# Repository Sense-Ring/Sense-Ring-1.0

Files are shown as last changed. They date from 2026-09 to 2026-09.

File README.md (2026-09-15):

# SenseRing

**Open-source smart ring for biosensing and motion tracking, packed into a format you can build, program, and improve.**

SenseRing is a compact, finger-worn research and development platform built around the Nordic Semiconductor [nRF52832](https://www.nordicsemi.com/Products/nRF52832) Bluetooth Low Energy SoC. Its custom electronics combine optical pulse sensing, motion sensing, wireless connectivity, battery charging, and power management in a wearable form factor.

Use it to explore photoplethysmography (PPG), heart-rate and SpO₂ algorithm development, activity and gesture recognition, low-power Bluetooth applications, and new wearable interfaces. 

<p align="center">
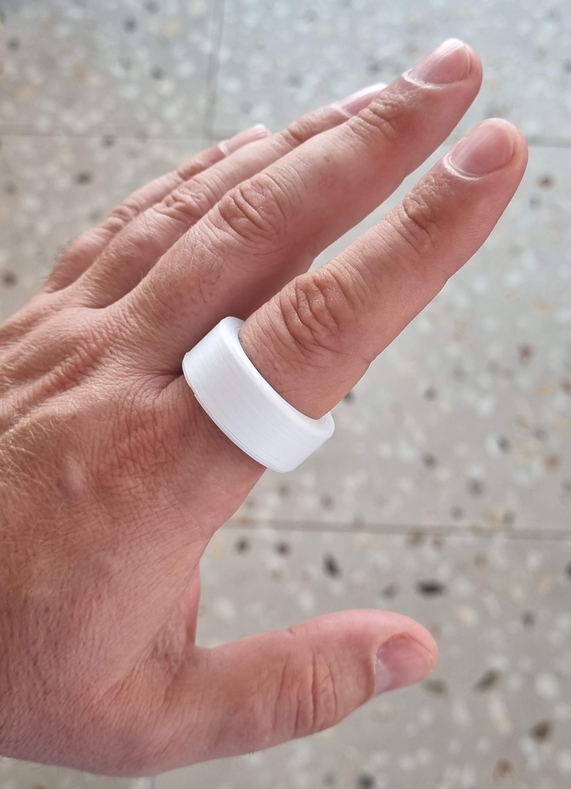
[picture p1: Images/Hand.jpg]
SenseRing 1.0 prototype worn on a finger
  
</p>

> [!IMPORTANT]
> SenseRing is an experimental research platform, not a certified medical device. Do not use it for diagnosis, treatment, or safety-critical monitoring.

## Hardware features

| Function | Implementation |
| --- | --- |
| Processing and wireless | [nRF52832](https://www.nordicsemi.com/Products/nRF52832), 64 MHz Arm Cortex-M4F with Bluetooth Low Energy and a 2.4 GHz radio |
| Optical sensing | [MAX30102](https://www.analog.com/en/products/max30102.html) integrated red/IR PPG sensor for pulse-oximetry and heart-rate experiments |
| Motion sensing | [BMA530](https://www.bosch-sensortec.com/en/products/motion-sensors/accelerometers/bma530) ultra-compact, low-power 3-axis accelerometer with motion interrupts and step-counting support |
| Battery charging | [BQ25180](https://www.ti.com/product/BQ25180) single-cell Li-ion/LiPo charger with I²C control, power path, and ship mode |
| Power and protection | [AP6683](https://www.lcsc.com/datasheet/C2849565.pdf) battery protection, [XC6504A1819R-G](https://www.lcsc.com/datasheet/C5142782.pdf) 1.8 V LDO, and two [WS4622C](https://www.lcsc.com/datasheet/C2939859.pdf) load switches for the PPG LED supply and battery-measurement circuit |
| RF front end | [2450AT18B100E](https://www.lcsc.com/datasheet/C2917717.pdf) 2.4 GHz chip antenna and matching circuit |
| Debugging and test | TC2030 SWD footprint for programming and charging, compatible with [Segger J-Link 6-pin Needle Adapters](https://www.segger.com/products/debug-probes/j-link/accessories/adapters/6-pin-needle-adapter/) |
|Battery| 31mAh curved [GRP1607034](https://www.grepow.com/wearables/smart-ring.html)|
| PCB | 14.9 × 10 mm, two copper layers, mostly fine-pitch WLCSP and 0201 components |

<p align="center">
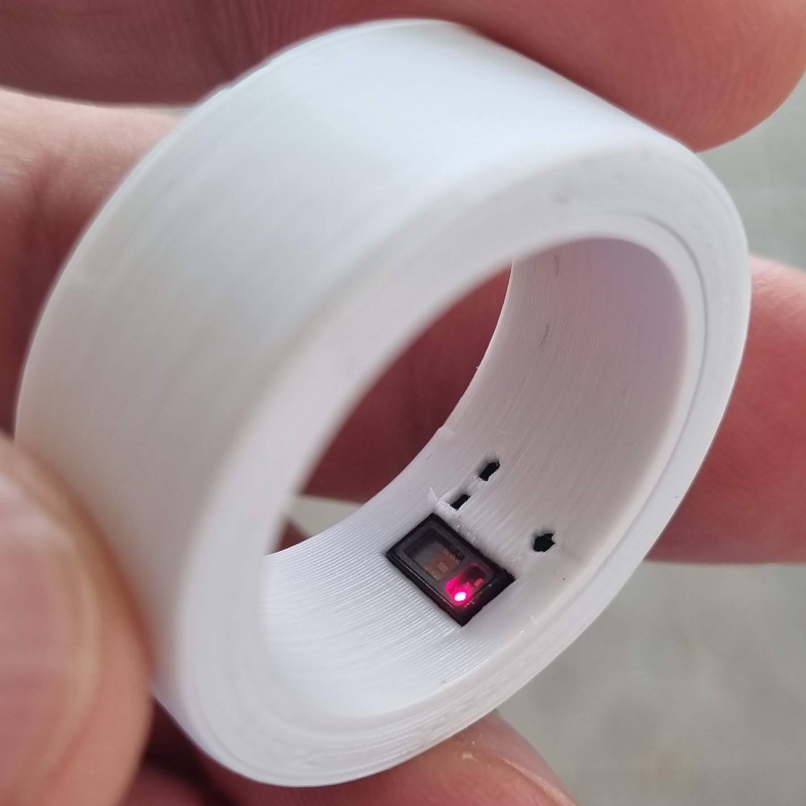
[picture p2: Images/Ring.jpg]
SenseRing optical sensor operating inside the ring
  
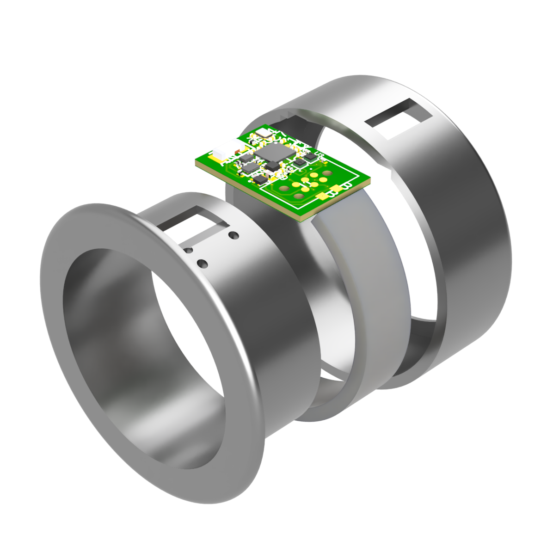
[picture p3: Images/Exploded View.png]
Exploded rendering of the SenseRing enclosure, battery, and circuit board
  
</p>

## Architecture

The nRF52832 communicates with the PPG sensor, accelerometer, and charger over a shared I²C bus. Dedicated interrupt lines allow the sensors and PMIC to wake the processor. The PPG LED supply and battery-measurement divider are independently switchable, limiting leakage when those functions are idle.

<p align="center">
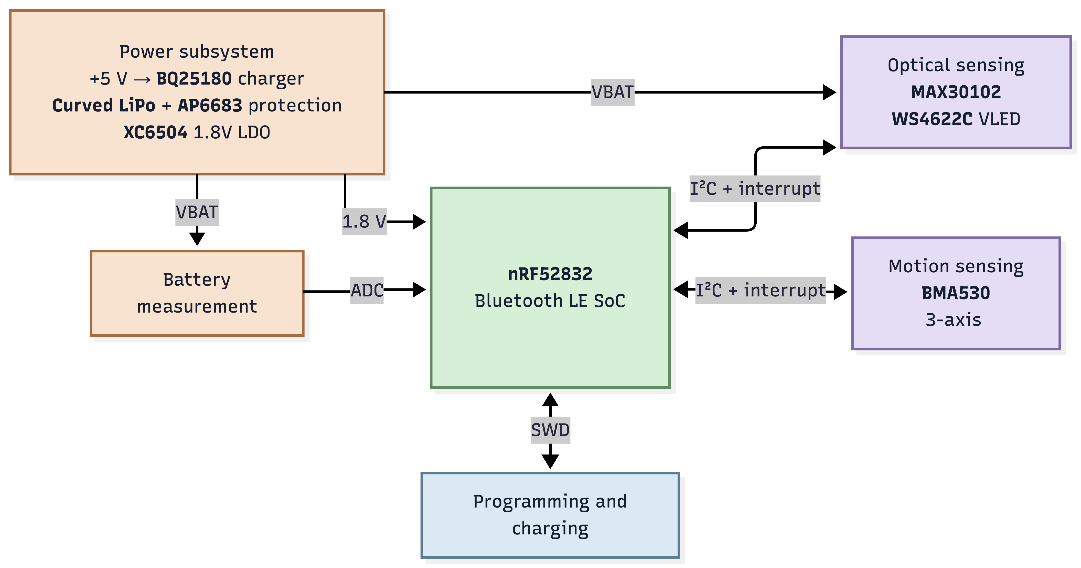
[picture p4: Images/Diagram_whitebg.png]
SenseRing 1.0 diagram
  
</p>

| Signal | nRF52832 pin | Connected function |
| --- | --- | --- |
| `SDA` | `P0.29 / AIN5` | MAX30102, BMA530, and BQ25180 data |
| `SCL` | `P0.28 / AIN4` | MAX30102, BMA530, and BQ25180 clock |
| `PPG_INT` | `P0.06` | MAX30102 interrupt |
| `IMU_INT` | `P0.18` | BMA530 interrupt |
| `PMIC_INT` | `P0.15` | BQ25180 interrupt |
| `LED_EN` | `P0.01` | PPG LED-rail load switch |
| `VBAT_EN` | `P0.00` | Battery-divider load switch |
| `VBAT_MEAS` | `P0.05 / AIN3` | Battery-voltage ADC input |
| `TX` test pad | `P0.30 / AIN6` | Firmware-assignable test/UART signal |
| `RX` test pad | `P0.25` | Firmware-assignable test/UART signal |

## Battery benchmark

Measured with a Power Profiler Kit II supplying the board in place of the 31 mAh cell, running the normal cycle: 15 s window, five readings, LED rail down, 90 s pause. IMU on throughout, BLE advertising. This replaces the estimate in [`ARCHITECTURE.md`](Software/Firmware/src/ARCHITECTURE.md) §5.1.1 (~305 µA, four days).

<p align="center">
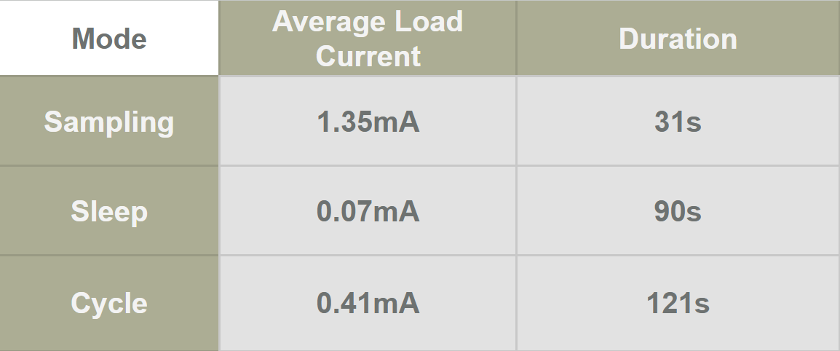
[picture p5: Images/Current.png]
Average load current per mode: 1.35 mA sampling, 0.07 mA sleep, 0.41 mA over the full cycle
  
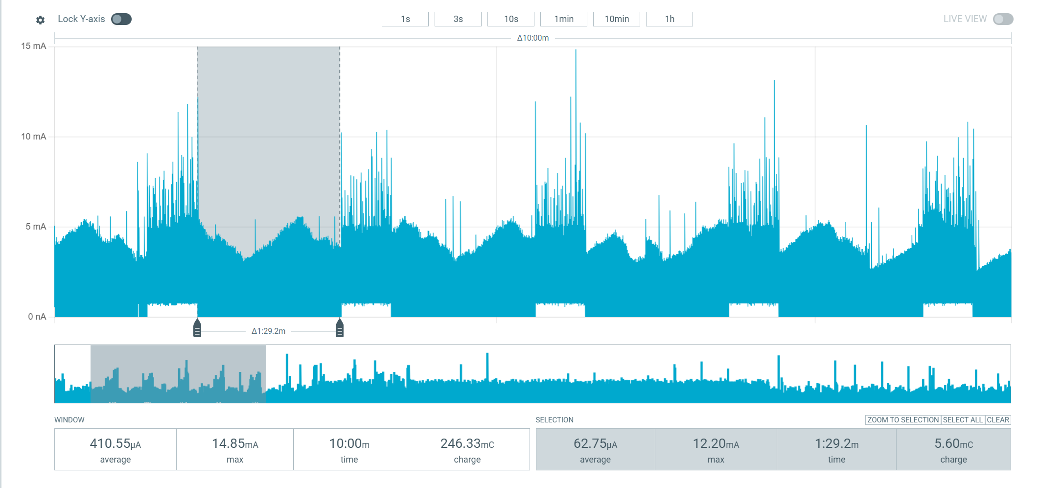
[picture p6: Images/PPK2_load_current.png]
Power Profiler Kit II capture of ten minutes of SenseRing load current
  
</p>

| Mode | Average load current | Duration |
| --- | --- | --- |
| Sampling (LED rail up) | 1.35 mA | 31 s |
| Sleep (IMU and BLE only) | 0.07 mA | 90 s |
| **Full cycle** | **0.41 mA** | **121 s** |

31 s of sampling against a 90 s pause is 25.6 % duty. Over ten minutes the capture reads 410.55 µA average, 246.33 mC, 14.85 mA peak. One full pause reads 62.75 µA: the BMA530 at ~15 µA, the nRF52832 idle, and both load switches open.

### Runtime on 31 mAh

| Quantity | Value |
| --- | --- |
| Charge per cycle | 13.7 µAh (~49 mC) |
| Cycles per charge | ~2,250 |
| Readings per charge | ~11,250 |
| **Runtime, default cadence** | **~75 h (3.1 days)** |
| Sampling continuously | ~23 h |
| Sleep floor only | ~440 h (18 days) |

## Repository contents

| Path | Contents |
| --- | --- |
| [`Hardware/`](Hardware/) | Autodesk Fusion Electronics/EAGLE schematic and board sources (`.fsch`, `.fbrd`, `.sch`, `.brd`) and a [schematic PDF](Hardware/SenseRing_schematic.pdf) |
| [`Mechanical/`](Mechanical/) | Complete Fusion 360 archive, STEP and OBJ assemblies, printable shell STLs, board and battery models, and two programming-fixture STLs |
| [`Images/`](Images/) | Prototype photographs and the exploded assembly render used in this README |
| [`Software/Firmware/`](Software/Firmware/) | nRF52832 firmware: sampling, the vitals estimator, the flash log, and the BLE peripheral |
| [`Software/App/`](Software/App/) | Android companion app: collects the ring's buffered log over BLE, stores it locally and charts it |

## Working with the design

### 1. Clone the repository

```bash
git clone https://github.com/Sense-Ring/Sense-Ring-1.0.git
cd Sense-Ring-1.0
```

### 2. Inspect or modify the electronics

- Open [`SenseRing.fsch`](Hardware/SenseRing.fsch) and [`SenseRing.fbrd`](Hardware/SenseRing.fbrd) in Autodesk Fusion Electronics.
- The XML [`SenseRing.sch`](Hardware/SenseRing.sch) and [`SenseRing.brd`](Hardware/SenseRing.brd) files are also included for EAGLE-compatible workflows.
- For a quick review without CAD software, open [`SenseRing_schematic.pdf`](Hardware/SenseRing_schematic.pdf).

### 3. Inspect or print the enclosure

- Open [`RingCase.f3z`](Mechanical/RingCase.f3z) for the editable Fusion 360 assembly.
- Use [`RingCase.step`](Mechanical/RingCase.step) or [`RingCase.obj`](Mechanical/RingCase.obj) for interchange with other CAD tools.
- Print [`InnerShell.stl`](Mechanical/InnerShell.stl) and [`OuterShell.stl`](Mechanical/OuterShell.stl) for the enclosure.
- The repository also provides board and battery reference models and two-piece programming-fixture STLs.

### 4. Program and debug

The PCB exposes `SWDIO`, `SWDCLK`, `RESET`, 1.8 V, +5 V, and GND through its TC2030 programming footprint. Use a compatible SWD debugger and verify the target-voltage and power configuration before connecting it to the board.

## Manufacturing notes

This is a miniaturized wearable design using WLCSP/BGA packages and 0201 passives. Professional PCB assembly and appropriate inspection equipment are strongly recommended.

The current repository does **not** include production exports such as Gerbers, drill files, a bill of materials, or pick-and-place data. Generate and verify those outputs from the hardware sources before ordering boards. Battery selection, charge settings, clearances, enclosure material, skin contact, RF performance, and optical performance must all be validated for your implementation.

## Contributing

Issues, design reviews, firmware ports, enclosure variants, measurements, and reproducibility notes are welcome. When reporting a hardware problem, please include the board revision, power source, programmer/debugger, and enough measurements or logs to reproduce it.

## License

SenseRing 1.0 is open source and distributed under the [GNU General Public License v3.0](LICENSE). It is provided as-is, without warranty.

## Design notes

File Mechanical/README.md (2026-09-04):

Mechanical files for the ring case, programming fixture and board+battery.

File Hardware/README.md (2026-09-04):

Hardware design files for Fusion 360 / Eagle CAD

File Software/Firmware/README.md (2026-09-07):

# SenseRing firmware

Zephyr OS app for the SenseRing 1.0: an nRF52832 that measures heart rate and blood
oxygen from the finger, stores every reading to on-board flash, and hands the
log to a phone over Bluetooth.

The ring never decides what a reading means. It measures, records *why* it
refused when it could not measure, and buffers until something collects.

## How it works, in five lines

- Two LEDs and a photodiode (MAX30102) sample the finger at 25 Hz.
- Every ~2 minutes the ring wakes, fills a 15-second window, and reports five
  readings from it, then puts the LEDs down. That is ~26% duty on a 31 mAh cell.
- Autocorrelation over the window gives the pulse period and a 0–1000
  confidence; the red/IR ratio gives SpO₂.
- Each reading becomes a 16-byte record in a flash ring buffer — about **4 days**
  of readings, 14,592 records — carrying its own confidence, perfusion, contact
  state, step delta and movement bucket.
- A client subscribes over BLE, replays the backlog, and acknowledges it. Only
  then does the ring erase.

An accelerometer (BMA530) runs continuously at ~15 µA: it decides when the hand
is still enough to be worth measuring, and tags every record with how much it
moved.

**`src/ARCHITECTURE.md` is the real documentation** — one section per source
file, explaining the reasoning rather than restating the code. Start at §0 if
embedded work is new to you.

## Hardware

Board `sensering_v29`, defined in-tree under `boards/`. The schematic this
firmware was written against is `.sense/SenseRing v49.pdf`, and it is the
authority whenever it and a document disagree — the version numbers differ, and
the schematic is the one that matches the pinout. The repository's own hardware
sources live in [`Hardware/`](../../Hardware/).

| | |
|---|---|
| MCU | nRF52832 (QFAA), 512 KB flash / 64 KB RAM, no DC/DC inductor |
| PPG | MAX30102, I²C `0x57`, on a switched VLED+ rail |
| IMU | BMA530, I²C `0x18` |
| PMIC | BQ25180, 31 mAh LiPo |
| Rail | XC6504 1.8 V LDO |
| Console | **RTT only — the board has no UART** |

## Building

The toolchain is the nRF Connect SDK (Zephyr). Built against **NCS v3.3.1**.

```
west build -b sensering_v29 -- -DBOARD_ROOT=<path to this repo>
```

`build_env.bat` wraps that for a Windows-side NCS install — edit the two NCS
paths at the top; it works out the repo location itself. It exists because `west` and the toolchain live on the
Windows side, so builds have to run through `cmd.exe` rather than from a WSL
shell with exported variables — bash environment variables do not propagate to
Windows processes.

A clean build currently produces:

```
FLASH:  209 232 B / 248 KB   82.4%
RAM:     43 428 B /  64 KB   66.3%
```

The `mcuboot` and `image-0` partitions remain in the map and the app links over
them; the former OTA slots were reclaimed for the vitals log, so **there is no
OTA path** — flashing needs a J-Link.

```
west flash          # J-Link, nRF52832_xxAA at 1000 kHz
```

## Tests

The pure-arithmetic halves run on a host compiler in about a second, with no
Zephyr, board or NCS toolchain:

```
cd tests/host
make            # everything      — 63,377 checks
make vitals     # the rate estimator, against synthetic PPG
make flash      # the log's ring arithmetic, against a modelled NOR part
make sweep      # candidate BPM floors side by side
```

The flash model only ever clears bits, exactly like the part, so writing into a
slot nobody erased first fails the way hardware fails. Neither target is wired
into `CMakeLists.txt` — deliberately, because a test that needs the full
toolchain is a test nobody runs. Nothing covers the duty cycle or the BLE
protocol; both need a kernel.

`tests/bench/` holds bring-up modes that are kept but not compiled — an I²C bus
scan and IMU probe, for a board revision that fails to come up.

## Bluetooth

Standard Heart Rate (`0x180D`) and Battery services, plus a custom service at
`f1a00001-9c1b-4d3e-a7b2-5e8c6d9f0a11`:

| Characteristic | Purpose |
|---|---|
| `…0002` | live vitals package — byte-identical to the flash record |
| `…0003` | live motion — timestamp, x/y/z, step total |
| `…0004` | control — set the clock, request a replay, acknowledge one |
| `…0005` | history — the framed, resumable backlog replay |
| `…0006` | status — cell level and step total |

The custom characteristics are encryption-gated and bonds persist. The ring
decides who may pair: only with no bond yet, or inside a two-minute window
opened by a power-on boot.

Live streaming is **off** by default (`BLE_LIVE_STREAM` in `main.c`) — the radio
carries nothing per reading, and data leaves in page-sized batches.

## Licence

This firmware is MIT — see [`LICENSE`](LICENSE). The SenseRing 1.0 repository as
a whole is GPLv3; MIT is compatible with that, so a combined work still
distributes under the GPL.

## Layout

```
src/            firmware, one .c per subsystem, plus ARCHITECTURE.md
boards/         the sensering_v29 board definition and DTS
tests/host/     host-compiled tests for vitals.c and flash_store.c
tests/bench/    uncompiled bring-up helpers
prj.conf        Kconfig, every line commented with why
.sense/         schematic
LICENSE         MIT
```

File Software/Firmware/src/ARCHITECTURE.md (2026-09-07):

# SenseRing firmware — how `src/` works and why

**New here? Read §0 in full. It assumes no embedded experience and it is the
only part of this document that doesn't.** Everything after it is a reference
manual: one section per source file, explaining the reasoning rather than
restating the code. Read those next to the source; the headings match the
function names.

Written against the **v49 schematic** (`.sense/SenseRing v49.pdf`) and
`boards/sensering_v29/sensering_v29.dts`. The version numbers disagree — v49 is
the one that matches the pinout, and the schematic is the authority whenever it
and this document differ.

---

## 0. Start here

### 0.1 What the thing is

A ring that measures the wearer's heart rate and blood oxygen every couple of
minutes, stores the readings, and hands them to a phone.

That's it. Everything below is consequence.

The ring cannot reach the internet, so it talks to a phone over Bluetooth, and
whatever the phone is connected to decides what the readings mean.

```
  ring  ──Bluetooth──>  phone  ──> whatever consumes the data
 measures               relays
 and stores
```

### 0.2 Two ideas explain most of the code

**Idea one: the battery is 31 milliamp-hours.** For scale, a phone battery is
about 4000. If the ring drew what a phone draws it would last under a minute.
So the ring spends most of its life asleep with everything switched off, wakes
up, measures for half a minute, and goes back to sleep. Almost every strange
decision in this codebase — why the LEDs are on a switch, why the radio listens
only once a second, why a measurement is 15 seconds and not 60 — traces back to
this number.

**Idea two: the ring is not the decider.** It is tempting to make the ring
clever: have it interpret the readings it takes. It does not. The ring measures,
stores, and says "come and get the data." Interpretation belongs to whatever
consumes the log, because that can be updated, can see history, and can be
wrong without a firmware release.

This is why you will see the code repeatedly refuse to draw conclusions, and why
it works so hard to record *why* it refused rather than just going quiet. The
one judgement it does make is about its own evidence -- whether a window
produced a pulse it believes -- and §4.5 is where that line is drawn.

### 0.3 How a heart rate actually gets measured

No prior knowledge needed for this; it is genuinely simple in outline.

1. **Shine a light into the finger.** Two LEDs, one red and one infrared, sit
   against the skin. A photodiode next to them measures how much light comes
   back. This is the MAX30102 part, driven by `ppg.c`.
2. **Blood absorbs light.** Every heartbeat pushes a pulse of blood through the
   finger, so slightly less light comes back at each beat. The signal is a big
   steady value with a *tiny* ripple on it — the ripple is well under 1% of the
   total on a ring. That ripple is the pulse.
3. **Collect 15 seconds of it.** At 25 samples a second that's 375 numbers.
4. **Throw away the slow drift.** Breathing moves the signal far more than the
   heartbeat does, so a filter removes anything slower than a plausible pulse.
5. **Find the repeat.** Slide the 15 seconds of signal against itself and see
   at what shift it best matches itself. That shift is the time between beats.
   60 divided by it is the heart rate. This is `vitals.c`, and it is called
   *autocorrelation*.
6. **Say how sure you are.** How well the signal matched itself is a confidence
   number, 0–1000. Below 500 the firmware will not call it a heart rate.

Blood oxygen (SpO₂) rides along free: oxygenated blood absorbs red and infrared
differently, so the ratio of the two ripples tracks saturation.

### 0.4 What happens to a reading

```
  measure ──> is it believable? ──yes──> write to flash ──> notify phone (live)
                     │
                     └──no──> write the *refusal* to flash, with the reason
```

Two things worth understanding, because they are unusual:

**Refusals are stored, not skipped.** If the ring is not being worn, or the
pulse is too weak, the firmware writes a record saying so. A log with a hole in
it and a log that says "I looked and saw nothing" look identical from the
outside, and only one of them is useful. The reasons are: not worn, no pulse
found, pulse too weak, and pulse slower than the band.

**Flash is a queue, not a diary.** Records go into a ring buffer in flash and
stay there until the phone confirms it has them. Only then does the ring reuse
that space. If the phone is away for a day, the readings wait. This is the
"buffer and flush" architecture, and §5A is where it lives.

### 0.5 Vocabulary

The terms that will otherwise stop you, in the order you'll meet them. Appendix
B is the full glossary.

| Term | What it means here |
|---|---|
| **PPG** | photoplethysmography — the shine-a-light-at-a-finger technique in §0.3 |
| **I2C** | a two-wire bus the chip uses to talk to the sensors. Think of it as a very slow, very simple network with addresses |
| **GPIO** | a single pin the chip can drive high or low. Used here to switch sensor power on and off |
| **DC / AC** | the steady part of a signal / the ripple on top. The pulse is the AC part |
| **perfusion index (PI)** | how big the ripple is compared to the steady part, in parts per thousand. A ring sees ~0.2–1%; a fingertip clip sees ten times that |
| **duty cycle** | what fraction of the time something is switched on. The whole power budget is duty cycle arithmetic |
| **RTT** | a debug console that works over the programming cable. This board has no serial port, so RTT is the only way to watch it run |
| **GATT / characteristic** | Bluetooth's way of exposing named values a phone can read, write, or subscribe to |
| **notification** | the ring pushing a value to the phone without being asked |
| **flash page** | flash memory can be written a byte at a time but only *erased* a whole page (4KB) at a time. This one fact shapes all of `flash_store.c` |
| **Kconfig / `prj.conf`** | build-time switches for the operating system (Zephyr). Appendix C explains the ones that matter |

### 0.6 What to read next

| If you want to… | Read |
|---|---|
| See the board and the software in one page each | §1 |
| Understand a specific source file | §2–§5C, one per file, in dependency order |
| Know what is *not* built | §6 |
| Look up a pin | Appendix A |
| Look up a word | Appendix B |
| Understand the build, the board file, the partitions | Appendix C |

The per-file sections are `battery.c` §2, `ppg.c` §3, `imu.c` §3A, `vitals.c`
§4, `main.c` §5, `flash_store.c` §5A, `ble.c` §5B and `wallclock.c` §5C.

---

## 0A. What is measured, and what is only argued

Kept near the top because the rest of this document describes how things work,
which is a different question from how well they have been shown to.

**The short version: the ring measures correctly and the data path closes. The
power budget is the one number the whole design is argued from, and it has never
been put on a probe.**

### 0A.1 What is built, and what backs it

| Area | State | Evidence |
|---|---|---|
| Board bring-up — I2C, SAADC, flash, RTT, BLE | works on hardware | boots, advertises, logs, stores |
| `battery.c` — divider, gating, curve | works on hardware | reports plausible mV and % |
| `imu.c` — BMA530 read path | works on hardware | §3A; bus scan saw `0x18`, chip ID `0xC2`, \|a\| ≈ 1000 at rest |
| IMU step count | **wired up, never walked** | §3A.8; read and notified, but never checked against a human walking a known count |
| `vitals.c` — heart rate | works on hardware | 71bpm off a real finger, confidence and optics both plausible |
| `vitals.c` — the arithmetic | host-tested | `tests/host`, 1026 synthetic windows, 0 wrong |
| `vitals.c` — SpO₂ | **arithmetic sound, curve uncalibrated** | §4.4; Maxim's fit for Maxim's optics |
| Contact detection | **works, threshold still a guess** | §4.5; `VITALS_CONTACT_IR_DC_ON` has never been checked against a range of real fingers |
| Duty cycle, flash log | works on hardware | §5.1, §5A |
| `flash_store.c` — ring arithmetic, ack and erase | host-tested | `tests/host`, two laps at the real geometry against a modelled NOR part |
| `ble.c` — advertising, services, live notifications | works on hardware | §5B |
| `ble.c` — who may pair, who may stay connected | **written, never met a handset** | §5B.5a; the pairing gate and the 30-second security deadline both build clean, and neither has been exercised on the radio |
| **Buffer → phone → acknowledge → reclaim** | works on hardware | §5A.8, §5B.6 |
| Connection power (slave latency) | works on hardware | §5B.7; a real phone granted the idle regime |
| Power budget | **estimated, never measured** | §5.1.1 |

### 0A.2 The gap that matters

**Every power number in this document is arithmetic, not measurement.** §5.1.1
predicts ~305µA and about four days, and flags that its largest single term is
quoted at a shorter LED pulse width than this firmware actually uses — so the
real figure is likely worse. Until a current probe goes on the cell, every
decision justified by "this saves battery" is justified by a spreadsheet.

**Two worn observations say the spreadsheet is wrong by ~3.7×.** They implied
~2.1 and ~1.5 days respectively, both with about a third of the time off the
finger — so a worn-state draw near 1.14mA against a predicted 305µA. Both are
gauge readings, and the gauge itself is untrusted (§2.5), so treat ~1 day as a
direction rather than a measurement. The important part is the sign: **every
number in §5.1.1 is optimistic, and nothing in this document accounts for
why.**

### 0A.3 Known limits, in the order they would hurt

| | Limit | Where |
|---|---|---|
| 0 | **The ring can reset roughly every 28 minutes and the firmware cannot say why.** Observed at 60% battery and not under radio load. `RESETREAS`, a delivery hold mark and a log that survives a reset are all written against it, and the mechanism is still open — brownout, a supply interruption and the BQ25180 are all live. | §5A.1, §5A.4a |
| 1 | **No activity signal reaches the vitals path.** 120bpm from climbing stairs and 120bpm at rest are the same number to this firmware. Acceleration and step count are read, notified and stored beside the reading, but nothing on the ring *consumes* them. | §6 |
| 2 | **The power budget has never been measured.** | §5.1.1 |
| 3 | **SpO₂ is uncalibrated.** The ratio arithmetic is sound; mapping it to a percentage is a vendor fit for a different sensor's optics. Trend, not vital sign. | §4.4 |
| 4 | **The step counter has never been walked.** Presented as data on no evidence. | §3A.8 |
| 5 | **`VITALS_CONTACT_IR_DC_ON` decides whether the ring measures at all, and is a bench guess.** Every cycle logs the measured IR DC beside it, so a wrong threshold is visible rather than silent. | §5.1 |
| 6 | **The pairing gate rests on a bit that cannot tell a power cycle from a brownout.** `RESETREAS` reads zero for both, so a cell that sags far enough to reset the SoC opens a two-minute pairing window nobody asked for. Bounded, but it is the assumption the whole gate stands on. Beside it: Zephyr's stock HRS is still unencrypted, so `0x180D` is subscribable by any scanner the moment `BLE_LIVE_STREAM` goes to 1 for bench work. | §5B.5a, §6 |
| 7 | RTT is 4KB, `NO_BLOCK_SKIP` — raised from the 1KB a 35-record dump overran, but a full-page dump is still tens of KB and drops silently. | §5.5.1 |
| 8 | **Delivery depends on the phone being in range.** If the phone is in another room nothing arrives; the records are buffered and delivered later. This is a property of the architecture, not a bug in it, and it has to be stated to whoever builds on the device. | §5A.8 |

Item 0 is the one that stops the data being trustworthy at all. Item 1 is the
one that most limits what can be built on top of the log: without activity
context, a rate is a number with nothing to explain it. It is not a bug — it is
a consequence of a choice documented where it was made — but it is the widest
gap.

---

## 1. The system at a glance

The board is an nRF52832 driving three I2C peripherals, powered from a single
LiPo cell through a BQ25180 PMIC.

```mermaid
graph LR
    CELL["LiPo cell<br/>3.27–4.2V"] --> PMIC["BQ25180<br/>PMIC"]
    PMIC --> LDO["XC6504<br/>1.8V LDO"]
    LDO --> MCU["nRF52832"]
    LDO --> VDD["MAX30102 VDD<br/>(I2C side)"]

    CELL --> U3["U3 WS4622C<br/>load switch"]
    U3 -->|VLED+| LEDS["MAX30102<br/>RED + IR LEDs"]
    MCU -->|"LED_EN<br/>P0.01"| U3

    CELL --> U4["U4 WS4622C<br/>load switch"]
    U4 --> DIV["R5/R6 divider<br/>+ C21"]
    DIV -->|AIN3| SAADC["nRF52 SAADC"]
    MCU -->|"VBAT_EN<br/>P0.00"| U4

    MCU <-->|"I2C0 400kHz<br/>SDA P0.29 / SCL P0.28"| LEDS
```

The single most important structural fact about this board: **two separate
things hang off the raw cell behind two separate load switches.** Almost every
non-obvious decision in `battery.c` and `ppg.c` traces back to that.

### Why load switches at all?

A ring runs on a battery measured in single-digit mAh. Two loads would otherwise
draw current forever:

- **The divider.** R5 (1M5) + R6 (1M) = 2M5 across a 4.2V cell is a permanent
  1.68µA leak. That sounds trivial until you multiply by 24 hours — 40µAh/day,
  bleeding the cell whether the ring is worn or not.
- **The LEDs.** ~10mA each while pulsing. Obviously must be gated.

So the schematic puts a **WS4622C load switch** in front of each: U3 for the LED
rail, U4 for the divider. Both are active-high enables. Firmware's job is to
hold them open by default and close them only for the microseconds it actually
needs.

This is why you'll see the same shape in both files: *enable → settle → use →
disable*, with the disable on the error path too.

### The subtlety that shapes `ppg.c`

The MAX30102 has **two power inputs**: `VDD` (1.8V, from the LDO — always on)
and `VLED+` (raw cell, behind U3). The I2C interface lives on the VDD side.

That means **the chip answers I2C even while its LEDs are unpowered.** You can
read the part ID, configure registers, and get perfectly valid-looking responses
from a sensor that is optically dead. There is no error code for "the LEDs
aren't powered" — you just get flat data. Hence `ppg_init()` raises LED_EN
*before* it talks to the chip at all, and drops it again on every failure path.

### The cast of parts

Everything above in one table, then one paragraph each. The **designator** (U3,
R5, C21…) is the label silkscreened on the board and printed on the schematic;
`U` is a chip, `R` a resistor, `C` a capacitor. When this document says "U4" it
means one specific physical component you can point at.

| Designator | Part | In one line |
|---|---|---|
| U1 | nRF52832 | The microcontroller. Runs this firmware. |
| — | BQ25180 | The **PMIC** — charges the cell, feeds the board. |
| — | XC6504 | The **LDO** — makes a clean 1.8V rail for the chips. |
| U3 | WS4622C | **Load switch** — firmware-controlled on/off tap for the LED rail. |
| U4 | WS4622C | Same part, second copy — on/off tap for the battery divider. |
| — | MAX30102 | The **PPG** sensor: two LEDs and a photodiode. Reads your pulse. |
| AC2 | BMA530 | The **IMU** — an accelerometer. Read every package and used to gate the re-donning probe (§3A); nothing yet consumes it as a vital-sign input. |
| R5, R6 | 1M5 and 1M resistors | The **voltage divider** that scales the cell down for the ADC. |
| C21 | 1nF capacitor | Noise filter sitting on the divider's output. |
| — | LiPo cell | The battery. Single-digit mAh. |

**nRF52832** — the microcontroller (MCU), and the only thing here running
software. An ARM Cortex-M4 CPU at 64MHz with 512KB of flash (where the firmware
lives) and 64KB of RAM, plus a 2.4GHz Bluetooth Low Energy radio that `ble.c`
now drives (§5B). What makes it an *MCU* rather than a CPU is everything
bolted on beside the core: the SAADC, the I2C hardware, the GPIO pins. Those are
**peripherals** — fixed-function blocks the CPU configures by writing registers,
which then run on their own. The `QFAA` in the DTS filename is Nordic's code for
this specific flash/RAM/package variant.

**BQ25180 (the PMIC)** — *Power Management IC*. A LiPo cell is a fussy thing to
charge: too fast and it heats, too full and it degrades, too empty and it's
permanently damaged. The BQ25180 is a dedicated chip that does all of that
correctly in hardware — constant-current then constant-voltage charging, cutoff
at 4.2V, protection at the bottom. It has an I2C interface for status and
configuration, but firmware never opens it (§6): the chip's default behaviour is
already right, and charging keeps working even with the CPU asleep or crashed.

**XC6504 (the LDO)** — *Low-DropOut regulator*. The cell's voltage slides from
4.2V down to 3.27V as it discharges, but the nRF52832 needs a steady supply. An
LDO takes a varying higher voltage in and holds a fixed lower one out — here
1.8V. "Low dropout" means it only needs the input to be a little above the
output to keep regulating, which matters when the cell is nearly flat. The
trade-off: an LDO burns the difference as heat rather than converting it, so at
4.2V in / 1.8V out it wastes over half the energy. It's chosen anyway because a
switching regulator needs an inductor, and there is no room for an inductor
inside a ring.

**WS4622C ×2 (the load switches)** — a load switch is an electrically-operated
switch: power in one side, power out the other, and a logic-level **EN**
(enable) pin that decides whether the two are connected. Inside it's a MOSFET, a
transistor used as a switch. These are **active-high**: a `1` on EN connects,
`0` disconnects. It exists because a resistor or an LED cannot turn itself off —
something has to physically cut the current, and a GPIO pin can't supply the
10mA an LED needs. So the GPIO drives EN, and the switch does the heavy lifting.
This part also **actively discharges** its output when EN drops, pulling the
downstream rail to ground instead of letting it coast down — which is why §3.7
can say VLED+ collapses fast.

**MAX30102 (the PPG sensor)** — the part every reading comes from; see §3.1 for
what it does optically. Structurally the thing to know is that it's really two
circuits in one package that happen to share a die: a quiet digital side (the
I2C interface, the registers, the FIFO) running from 1.8V `VDD`, and a hungry
analog side (the LED drivers) running from raw cell voltage on `VLED+`. Those
two rails are independent, which is the whole subtlety described above.

**BMA530 (the IMU)** — *Inertial Measurement Unit*, a catch-all name for
motion-sensing chips. This one is a 3-axis **accelerometer**: it reports how hard
it's being accelerated along X, Y and Z. At rest that's just gravity, so it also
tells you which way is down and therefore how the ring is oriented. Here it is
used for movement context and for the re-donning probe (§3A.9, §5.3.1); the
chip also has a hardware step counter, which the firmware reads.

**R5 and R6 (the divider)** — two ordinary resistors in series between the cell
and ground: R5 is **1M5** (1.5 megohms, 1,500,000Ω) and R6 is **1M**. Wire two
resistors end to end across a voltage and the junction between them — the
**tap** — sits at a fraction of that voltage, set purely by the ratio of the two
values. That's a *voltage divider*: the cheapest possible way to shrink a
voltage into a range something else can measure. Here it makes 4.2V look like
1.68V, because the ADC cannot survive 4.2V on its input. The values are huge
(megohms) specifically to minimise the current wasted through them; §1's leak
arithmetic is what falls out of that choice, and §2.1 works the ratio.

**C21** — a 1nF (nanofarad) capacitor from the tap to ground. A capacitor
resists sudden changes in voltage, so parked on the tap it smooths away
electrical noise — including the ripple the LEDs inject into the cell every time
they pulse — and gives the ADC's input circuitry a small local charge reservoir
to sample from. It is also the reason a reading can't be taken instantly after
closing U4: the capacitor has to fill first. That's the 3ms in §2.4.

**The LiPo cell** — lithium-polymer, a single cell, so its terminal voltage runs
from 4.2V charged to about 3.27V empty and never gets divided or multiplied by
cell count. Capacity is quoted in **mAh** (milliamp-hours): a 10mAh cell can
supply 10mA for one hour, or 1mA for ten. That budget is why microamps of idle
leakage are a design concern here and would be a rounding error in a phone.

### The software at a glance

Eight `.c` files. The application is one thread that polls everything; the only
code here that runs on an interrupt or a second thread is the Bluetooth stack
underneath `ble.c`, and it is deliberately kept off the measuring path.

| File | Owns | Talks to hardware? | Section |
|---|---|---|---|
| `main.c` | Boot, the measurement cycle, the phase machine | No — delegates | §5 |
| `ppg.c` | The MAX30102: power, config, FIFO | I2C + GPIO (U3) | §3 |
| `imu.c` | The BMA530: power, config, acceleration, step count | I2C (no GPIO — no load switch) | §3A |
| `battery.c` | The cell voltage: divider, SAADC, curve | SAADC + GPIO (U4) | §2 |
| `vitals.c` | Counts → contact, heart rate, SpO₂ | **No.** Pure arithmetic | §4 |
| `flash_store.c` | Persisting each reading, and dumping the log | On-chip flash (storage partition) | §5A |
| `ble.c` | Advertising and the three GATT services | The radio, via Zephyr's BT stack | §5B |
| `wallclock.c` | The uptime → real-time anchor the phone sets | **No.** Two variables, no timer | §5C |

The dependency arrows all point one way, and the shape is deliberate:

```mermaid
graph TD
    MAIN["main.c<br/>the cycle"] --> PPG["ppg.c<br/>hardware"]
    MAIN --> BAT["battery.c<br/>hardware"]
    MAIN --> VIT["vitals.c<br/>arithmetic only"]
    MAIN --> FS["flash_store.c<br/>persistence"]
    MAIN --> BLE["ble.c<br/>radio"]
    BLE --> WC["wallclock.c<br/>arithmetic only"]
    PPG -.->|"struct ppg_sample"| VIT
    VIT -.->|"struct vitals"| MAIN
    MAIN -.->|"struct flash_sample"| FS
    FS -.->|"struct flash_sample"| BLE
    FS -.->|"battery_mv callback"| BAT

    style VIT fill:#e8f5e9,stroke:#2e7d32
    style WC fill:#e8f5e9,stroke:#2e7d32
    style MAIN fill:#e3f2fd,stroke:#1565c0
```

`flash_store.c` is the one edge that isn't strictly a tree: it calls back into
`battery.c` for a level to stamp on each flush (§5A). The call is handed in by
`main.c` as a function pointer, so `flash_store.c` still names no other module
directly.

Two edges do not start at `main.c`. `ble.c` owns `wallclock.c` because the clock
is only ever set from the radio — the control characteristic is the sole caller,
and routing it through `main.c` would add a hop that carries nothing. And
`ble.h` includes `flash_store.h` for `struct flash_sample`, which is deliberate
rather than a layering slip: the flash record and the vitals notification are one
layout by design (§5B.1), so the type that describes it is shared rather than
duplicated into two definitions that could drift.

`main.c` is the only file that knows how often a measurement happens. `ppg.c` is
the only file that knows a load switch exists. `vitals.c` doesn't know there's a
ring — it is handed a buffer by the caller and hands an answer back. The dotted
arrows are the structs
in the headers — the only data that crosses a file boundary — and they're the
whole interface:

```c
struct ppg_sample { uint32_t red, ir; };   /* ppg.h  — 18-bit counts, one FIFO entry */
struct vitals { bool contact; uint16_t bpm, confidence, spo2_tenths,
                perfusion_milli; uint32_t ir_dc; };  /* vitals.h — one window's answer */
```

**Why `vitals.c` gets to be the odd one out.** It is the file with no
`#include <zephyr/...>` for a driver, no logging, and no global state beyond its
own scratch buffers. That's not tidiness: it means it compiles on a laptop and
can be fed synthetic waveforms with known answers. That property found two real
bugs in `vitals.c` before the code ever reached the ring (§4.3) and one
systematic measurement error (§4.4). It is the
single highest-leverage structural decision in the codebase, and §4 exists mostly
to explain what it bought.

### The whole of runtime, in one page

```
boot
 ├── battery_init()      set up SAADC, leave the divider open          §2.3
 │                       └── fails → battery_ready = false, carry on.  §5.2
 ├── flash_store_init()  dump last run's log + battery, then erase     §5A
 ├── ble_init()          enable the controller, start advertising      §5B
 │                       └── fails → log it, carry on. Not a gate.     §5B
 ├── ppg_init()          verify the MAX30102, load config, leave dark  §3.4
 │                       └── fails → return from main(). No product.
 └── imu_init/start()    verify the BMA530, LPM 50Hz, leave it running §3A.9
                         └── fails → imu_ready = false, carry on.

loop — one measurement_cycle(), then a pause                          §5.1
 ├── ppg_start()          rail up, wake, warm up 100ms, clear FIFO     §3.5
 ├── PROBE   1s   probe_contact()   is there a finger here at all?     §5.4.1
 │    └── not worn → say what the IR DC was, ppg_stop(), pause.
 ├── PREPARE 15s  collect_for()     fill the sliding window            §5.4.2
 │    └── drain_once() → ppg_read_fifo(), every 200ms                  §3.6
 │         └── vitals_contact() per drain — a removal ends the cycle   §4.5
 ├── REPORT  15s  record_burst()    five packages, one every 3s        §5.5.2
 │    └── record_one()
 │         ├── vitals_compute()      DC → high-pass ×3 → smooth → correlate §4
 │         │    └── estimate_bpm()   autocorrelate, guard the octave   §4.3
 │         ├── flash_store_append()  persist the 16-byte record        §5A
 │         │    └── ...or _append_refusal() if the gate refused it     §5A.3
 │         ├── ble_notify_vitals()   HRS + the custom package          §5B
 │         └── imu_read()            one acceleration, same timestamp  §3A.9
 │              └── ble_notify_motion()  {timestamp, x, y, z}          §5B.1
 ├── ppg_stop()           SHDN, rail down                              §3.7
 ├── battery_read_mv()    close U4, settle 3ms, sample, open U4        §2.4
 │    └── battery_percent() → ble_set_battery()                        §2.5
 ├── flash_store_dump()   reprint what is new; erase nothing           §5A.7
 └── the wait                                                        §5.3
      ├── worn       → k_msleep(PAUSE_MS), 90s
      └── not worn   → wait_until_worth_probing(): poll the IMU,      §5.3.1
                       probe as soon as it moves, 90s backstop
```

`battery_init()` runs *before* `flash_store_init()` so the boot flush can stamp
a live battery level on the dump — see §5A.

Note what the leaves have in common: `vitals_compute()` and `battery_percent()`
take a buffer and a number respectively, and neither touches hardware. `main.c` does the driving; the leaves just answer.

Two numbers govern everything above: **15 seconds** (set by the physics of the
signal — §4.1) and the **90-second pause** between bursts (set by the power
budget — §5.1.1). They're independent, and §5.1.2 is about why you can't trade
one for the other.

**Memory.** `CONFIG_MAIN_STACK_SIZE` is 2048 bytes, and the buffers are much
bigger than that, so everything large is `static` — in `.bss`, not on the stack:

| Buffer | Where | Size |
|---|---|---|
| `window[375]` | `main.c` | 3KB |
| `ac_ir`, `ac_red`, `filter_tmp` — 375 `int32_t` each | `vitals.c` | 4.5KB |
| `batch[32]` | `main.c` | 256B |
| `discharge_curve[21]` | `battery.c` | 84B, and `const` — flash, not RAM |
| `buf[192]`, `corr[39]` | `ppg.c` / `vitals.c` | 192B / 156B, on-stack — small enough |

~7.8KB of static RAM out of 64KB from the application, and the Bluetooth stack
wants several KB more on top of that for its own buffers and thread stacks. On a
part this size that accounting isn't micro-optimisation, it's the difference
between booting and not — and it is the reason `VITALS_WINDOW_SEC` is a number
worth arguing about (§4.1) rather than one to round up for comfort.

---

## 2. `battery.c`

### 2.1 Why a divider, and why these values

The nRF52832 SAADC cannot read a 4.2V cell directly. Its input range is bounded
by `reference / gain`, and even the most permissive setting doesn't reach 4.2V.
So R5/R6 scale the cell down:

```
tap = VBAT × R6/(R5+R6) = VBAT × 1M/2M5 = VBAT × 0.4
```

A full 4.2V cell therefore presents **1.68V** at AIN3.

The DTS picks `ADC_GAIN_1_3` against `ADC_REF_INTERNAL` (0.6V):

```
full scale = 0.6V / (1/3) = 1.8V
```

1.68V into a 1.8V full scale — the cell covers 93% of the range with a little
headroom for a freshly-charged cell reading slightly high. That headroom is the
point: clipping at the top of the range would silently flat-line the reading at
100% exactly when you most want to trust it.

At 12-bit resolution, 1.8V/4096 = 0.44mV per count at the tap, which is 1.1mV
per count at the cell. The LiPo curve's tightest useful step (3.84V→3.82V, a
whole 5% of charge) is 20mV — roughly 18 counts. Plenty of resolution.

### 2.2 Why the DT node exists but the driver is disabled

`prj.conf` has `CONFIG_VOLTAGE_DIVIDER=n`, which looks contradictory next to a
`compatible = "voltage-divider"` node. It isn't, and this is worth understanding
because it's a trap:

Zephyr's in-tree voltage-divider **sensor driver** would bind to that node
automatically. But it only manages `power-gpios` through the PM device runtime
subsystem. Without the full PM stack enabled, that driver turns the divider on
at init and **never turns it off** — reintroducing exactly the 1.68µA leak U4
exists to prevent.

So the node stays (it's the canonical place to record the R5/R6 ratio, and
`VOLTAGE_DIVIDER_DT_SPEC_GET` reads it), but the driver is off and `battery.c`
gates U4 by hand.

The header `<zephyr/drivers/adc/voltage_divider.h>` still works with the driver
disabled — `VOLTAGE_DIVIDER_DT_SPEC_GET` and `voltage_divider_scale_dt` are
static inlines that only need the DT data, not the driver.

### 2.3 `battery_init()`

Three things, in order:

1. **Readiness checks** on the GPIO and the SAADC. These catch DTS/build
   mismatches at boot rather than producing mystery numbers later.
2. **`GPIO_OUTPUT_INACTIVE`** — configure the enable pin *and* drive it low in
   one call. The distinction matters: `GPIO_OUTPUT` alone would leave the pin at
   whatever the last state was. Inactive-by-default is the whole design.
3. **`adc_channel_setup_dt()`** — pushes the gain/reference/acquisition-time
   from the DTS into the peripheral. Done once; the per-read sequence only
   carries the things that change.

Returns a negative errno on failure so `main()` can decide what to do (and it
decides to keep going — see §5).

### 2.4 `battery_read_mv()` — the interesting one

```
  adc_sequence_init_dt   →  fill in channel/resolution/oversampling from DT
  gpio_pin_set_dt(1)     →  close U4, divider now sees the cell
  k_msleep(3)            →  let C21 charge
  adc_read_dt            →  sample
  gpio_pin_set_dt(0)     →  open U4 unconditionally
  MAX(raw, 0)            →  clamp
  adc_raw_to_millivolts  →  counts → mV at the tap
  voltage_divider_scale  →  mV at the tap → mV at the cell
```

**Why the sequence struct is initialized in that order.** `buffer`,
`buffer_size` and `calibrate` are set in the initializer;
`adc_sequence_init_dt()` then fills in `channels`, `resolution` and
`oversampling` from the DT spec. It only writes those three fields, so the
initializer's values survive. This is a real Zephyr API contract, not a
coincidence — but it's why the call order can't be flipped.

**Why `.calibrate = true` every read.** SAADC offset drifts with die
temperature, and a ring warms from ambient to skin temperature over minutes of
wear. Calibration costs ~120µs once every 10 seconds. Free, effectively.

**Why the 3ms sleep.** This is the part worth internalizing. C21 (1nF) sits on
the tap. When U4 closes, the divider charges it through the Thevenin resistance
of the two legs in parallel:

```
R5 ∥ R6 = (1M5 × 1M)/2M5 = 600kΩ
τ = 600kΩ × 1nF = 600µs
```

Between readings the switch is open and C21 discharges through R6 (τ = 1ms) —
over a 10-second gap it's fully drained. So **every reading starts from 0V** and
has to charge all the way up. 3ms is 5τ, which settles to within 0.67%.

> ⚠️ **Known imprecision.** 0.67% of 1.68V is ~11mV at the tap, i.e. **~28mV at
> the cell — always reading low.** On the flat middle of the LiPo curve, 28mV is
> worth ~7 percentage points of reported charge. Raising `VBAT_SETTLE_MS` to 7
> (≈12τ) drops the residual to a few ppm and costs 4ms per cycle. See §6.

**Why the GPIO drops before the error check.** The `(void)gpio_pin_set_dt(...)`
sits *above* `if (ret != 0)` deliberately. If the ADC read fails and we returned
early, U4 would stay closed and the divider would leak for the rest of the
device's life. Failure paths are exactly when you least want a latched-on
switch. The `(void)` cast marks the return as intentionally ignored — there's
nothing useful to do if turning a pin off fails.

**Why `MAX(raw, 0)`.** The SAADC in single-ended mode can return small negative
counts near zero input — it's a documented nRF behaviour, not a bug. Feeding a
negative into the millivolt conversion produces nonsense, so clamp first.

**Why `tap_mv` is reused for both.** `adc_raw_to_millivolts_dt()` converts in
place (counts → tap mV), then `voltage_divider_scale_dt()` converts in place
again (tap mV → cell mV) using the R5/R6 ratio from the DT. The variable holds
two different quantities at two different times, which is why it's worth reading
that pair of calls as a unit.

### 2.5 `battery_percent()` — why a lookup table

This is the part people usually get wrong, so it's worth spelling out.

A LiPo discharge curve is not a line. It looks like this:

```
4.2V ┤●●
     │   ●●●
4.0V ┤       ●●●
     │           ●●●●●●●●●●●●●●●●●●●          ← the flat part: 3.85→3.75V
3.8V ┤                            ●●●●●●●●●     covers ~50% of the charge
     │                                     ●●
3.6V ┤                                       ●●
     │                                         ●
3.4V ┤                                          ●
     │                                          ●
3.2V ┤                                          ●  ← the cliff
     └──────────────────────────────────────────────
     100%                                        0%
```

The middle is nearly flat. A linear fit from 4.2V to 3.27V would report ~50% for
most of the cell's usable life and then fall off a cliff with no warning, which
is the worst possible shape for a gauge to have. The device would claim half a
battery an hour before going dark.

So `discharge_curve[]` samples the real curve at 21 points, dense where it
matters. The lookup:

1. **Above 4200mV** → clamp to 100%. A cell on the charger reads higher than its
   open-circuit voltage; without this, `battery_percent()` could return >100.
2. **Walk down** from `i = 1` looking for the first entry the voltage is at or
   above. That entry and the one before it bracket the reading.
3. **Interpolate linearly between the two bracketing points.** The curve is
   piecewise-linear-ish at this density, so straight-line interpolation *within
   a segment* is accurate even though it's hopeless across the whole range.

```c
return discharge_curve[i].percent
     + ((mv - discharge_curve[i].mv) * span_pct) / span_mv;
```

Read that as: *start at the lower bracket's percentage, then add the fraction of
the way up this segment.* The multiply happens before the divide so integer
truncation only bites once, at the end.

4. **Fall through to 0%** — below 3270mV the cell is done.

The table is `static const` — it lives in flash, not RAM. On a 64KB-RAM part
that's not a micro-optimisation, it's table stakes.

**Reading the table.** The entries are open-circuit millivolts against remaining
charge, descending, and the density is the message: 3850→3750mV is *nine* entries
covering 30 percentage points, while 3610→3270mV is a single entry covering the
last 5%. That's not sloppiness at the bottom — below 3.6V the cell falls so fast
that interpolating finely would be pretending to a precision the chemistry
doesn't have. The dense middle is where a percentage point actually costs
millivolts, and where a coarse table would lie.

### 2.6 `battery.h` — the shape of the contract

Three functions, and the split between them is the point:

```c
int     battery_init(void);          /* 0 or negative errno */
int     battery_read_mv(void);       /* millivolts, or negative errno */
uint8_t battery_percent(uint16_t mv);/* 0–100, always */
```

**Why `battery_percent()` is separate from `battery_read_mv()`.** They could
obviously be one call. Keeping them apart means the curve lookup is a pure
function of a number — no hardware, no failure mode, no errno — so it can be
reasoned about and tested on its own, exactly like `vitals.c` (§4). It also means
`main.c` can log *both* the percentage and the raw millivolts, which is what you
actually want when the reported charge looks wrong and you need to know whether
to suspect the curve or the ADC.

**The one wart.** `battery_read_mv()` returns `int` (so it can carry a negative
errno) and `battery_percent()` takes `uint16_t`. `main.c` passes one to the other
after checking `mv >= 0`, which narrows `int` → `uint16_t` implicitly. It's safe
— the check rules out negatives and a cell can't reach 65535mV — but the
safety lives in the caller, not the types. Worth knowing before someone calls
`battery_percent()` from somewhere new without the check.

---

## 3. `ppg.c`

### 3.1 What the MAX30102 actually does

It's a pulse-oximetry front end: two LEDs (red ~660nm, IR ~880nm) and one
photodiode. It pulses each LED in turn, measures reflected light with an 18-bit
ADC, and pushes results into a 32-entry FIFO. Blood volume in the capillaries
changes with each heartbeat, which changes reflectance — that's the signal.

You don't read a heart rate out of it. You read raw light levels and do the DSP
yourself — that's §4.

### 3.2 Register configuration, bit by bit

The `#define`s pack multiple fields into single bytes. Here's the decode.

**`FIFO_CONFIG_VALUE = (0x01 << 5) | BIT(4)` = `0x30`**

| Bits | Field | Value | Meaning |
|---|---|---|---|
| 7:5 | `SMP_AVE` | `001` | average 2 samples |
| 4 | `FIFO_ROLLOVER_EN` | `1` | overwrite oldest when full |
| 3:0 | `FIFO_A_FULL` | `0000` | almost-full threshold (unused; we poll) |

`FIFO_ROLLOVER_EN` is load-bearing. **Without it the FIFO stops dead the first
time it fills and never restarts** — one missed poll and the sensor is bricked
until reset. With it, falling behind costs you old samples and nothing else.
That's the right trade for a heart-rate signal, where stale data is worthless
anyway.

**`SPO2_CONFIG_VALUE = (0x01 << 5) | (0x00 << 2) | 0x03` = `0x23`**

| Bits | Field | Value | Meaning |
|---|---|---|---|
| 6:5 | `SPO2_ADC_RGE` | `01` | 4096nA full scale |
| 4:2 | `SPO2_SR` | `000` | 50 samples/sec |
| 1:0 | `LED_PW` | `11` | 411µs pulse width, **18-bit resolution** |

`LED_PW` is the one to notice: pulse width and ADC resolution are the *same
setting* on this part. 411µs is the longest, and it's the only one that gives
the full 18 bits. Shorter pulses save power but throw away bits.

Combined with `SMP_AVE = 2` above: **50Hz ÷ 2 = 25Hz output rate**, which is
`PPG_SAMPLE_RATE_HZ` in `ppg.h` and the number everything downstream derives
its timing from.

**Why 50Hz and not 100Hz.** An LED costs energy in proportion to how long it is
lit, and it is lit `LED_PW` per conversion. Halving the conversion rate halves
LED on-time from 8.2% to 4.1% of wall-clock and halves the LED energy exactly.
Nothing is given up in exchange as long as 25Hz can still resolve a heartbeat,
and it can: 220bpm is 3.7Hz, so Nyquist wants ≥7.4Hz and 25Hz clears it three
times over. What 25Hz *does* cost is quantisation of the *period* — at 25Hz the
gap between adjacent lag values is 2.4bpm at rest and worse at speed. §4.3 buys
that back in software rather than paying for it in LED current.

**Why `LED_PW` stays at 411µs.** It's the obvious next power knob — 118µs would
cut LED energy another 3.5× — and it is deliberately not turned. A ring reflects
far less light back than a fingertip clip does, so the returned signal is weak
and the bottom bits are where the pulse actually lives. Bits are worth more than
microamps here. If the duty cycle in §5.1 ever proves insufficient, this is the
next thing to spend, and it's a `#define` for that reason.

**`LED_CURRENT_RED/IR = 0x32`** — drive current is 0.2mA per step, so
0x32 (50) × 0.2mA = **10mA**. A reasonable starting point for a ring pressed
against skin. If the DC level comes back too low to see a pulse, this is the
knob — it's a `#define` for exactly that reason.

**`MODE_SPO2 = 0x03`** — enables both RED and IR. Writing this is what starts
the LEDs pulsing, so it is deliberately *not* in `ppg_init()`'s config array:
it belongs to `ppg_start()` (§3.5), which is the only thing that should ever
light an LED.

### 3.3 `max30102_reset()`

Writes `MODE_CONFIG_RESET` (bit 6) and then polls for it to clear. The chip
clears the bit itself once the register bank is back to defaults — there's no
"reset done" interrupt, so polling is the only option.

The loop is 20 iterations of 5ms = 100ms of patience before `-ETIMEDOUT`. The
part resets in well under 10ms; the margin is there because a chip that needs
more than 100ms is broken, not slow, and we'd rather report that than hang.

Note the sleep comes *before* the read: right after the reset write the chip may
not be ready to answer at all.

### 3.4 `ppg_init()` — order matters

```
  gpio_is_ready / device_is_ready   →  fail fast on DTS mismatch
  gpio_pin_configure(ACTIVE)        →  close U3, VLED+ rises
  k_msleep(5)                       →  bulk caps charge
  read PART_ID                      →  is anyone home? is it the right chip?
  max30102_reset()                  →  known state
  write config[]                    →  FIFO, SpO2 rate, LED currents
  ppg_stop()                        →  SHDN, and the rail back down
```

**Why it ends with the rail down.** `ppg_init()` runs once at boot and the first
measurement window is up to a minute later. Leaving the LEDs lit across that gap
would spend the entire duty-cycle saving before the device has measured
anything. So init proves the hardware works and then puts it away: configured,
verified, dark.

**Why power comes before the part ID read.** Covered in §1, *The subtlety that
shapes `ppg.c`* — the chip would
answer over I2C regardless, so reading the ID while unpowered would "succeed"
and leave you debugging flat optical data later. Powering first means the ID
read is also a rail check.

**Why 5ms.** U3 switches in ~70µs, but VLED+ carries ~11µF of bulk capacitance
that has to charge through it. 5ms is generous; it happens once at boot.

**Why check the part ID at all.** The MAX30102 answers at I2C address 0x57, and
so does its sibling the MAX30105 — and so do several unrelated parts. `0x15`
confirms it's the chip this driver was written for. Without this check a wrong
part produces plausible-looking garbage.

**What's in the config array, and what isn't.** Everything here is a setting
that must already be correct before the first conversion ever happens: FIFO
behaviour, sample rate, LED currents. `MODE_CONFIG` is conspicuously absent —
writing it starts the LEDs, and that is now `ppg_start()`'s job. The FIFO
pointer resets are gone from here too, for the same reason: they belong with
the thing that starts a window, not the thing that runs once at boot.

Expressing the rest as a table rather than four `i2c_reg_write_byte_dt()` calls
keeps the error handling in one place.

**The `goto power_off` pattern.** Every failure after the rail comes up jumps
there and drops LED_EN. Same principle as the battery GPIO: never leave a switch
latched on down an error path. `goto` for cleanup is idiomatic C and idiomatic
Zephyr — it's the one use of `goto` that makes code clearer.

### 3.5 `ppg_start()` — waking up cleanly

The counterpart to `ppg_stop()`, and the only function that lights an LED.

```
  gpio_pin_set_dt(1)     →  close U3, VLED+ rises
  k_msleep(5)            →  bulk caps charge
  write MODE_SPO2        →  clears SHDN and starts the LEDs in one write
  k_msleep(100)          →  let the transient happen
  fifo_reset()           →  ...then throw it away
```

**Why one write starts it.** Shutdown retains every register on this part, so
the configuration `ppg_init()` loaded is still sitting there a minute later.
`MODE_CONFIG` carries both the `SHDN` bit and the mode field, so a single write
of `MODE_SPO2` clears shutdown *and* selects RED+IR. There's no need to re-send
the configuration on every window, and doing so would be ~8 needless I2C
transactions a minute.

**Why the FIFO is cleared *after* the warm-up rather than before.** This is the
ordering that matters. The first conversions after a rail comes up ride the
settling transient — they're real samples of a not-yet-settled optical path. If
they lead the window, the DC mean in §4.2 is computed partly from a ramp, and
what's left after subtracting it is a trend the filters read as signal. So
`ppg_start()` lets the transient happen, waits it out, and *then* zeroes the
pointers underneath it. The FIFO forgets, and the window begins at the first
settled sample. 100ms against a 15-second window is 0.7% overhead for a
guarantee that the data starts clean — and against a 31-second burst, which is
what actually pays it (§5.1.2), less than that.

### 3.6 `ppg_read_fifo()` — the pointer arithmetic

This is the densest function in the codebase. The FIFO is a **circular buffer**
with three registers describing it:

```
  REG_FIFO_WR_PTR  (0x04)   where the chip will write next
  REG_OVF_COUNTER  (0x05)   how many samples were lost to overflow
  REG_FIFO_RD_PTR  (0x06)   where we will read next
```

They're contiguous, so **one burst read gets all three atomically**. This isn't
just efficiency: three separate reads could catch the write pointer advancing
mid-sequence and compute a nonsense count.

```c
available = (ptrs[0] - ptrs[2]) & FIFO_PTR_MASK;
```

The pointers are 5-bit (0–31) and wrap. Subtracting and masking with `0x1F` does
**modular arithmetic**: it gives the right distance even when the write pointer
has wrapped past the read pointer. If WR=2 and RD=30, `(2-30) & 0x1F` = 4 — the
four samples at positions 30, 31, 0, 1. The naive `WR - RD` would give -28.

**The ambiguity, and why `OVF_COUNTER` resolves it.** When WR == RD the distance
is 0 — but that's true in *two* different situations: the FIFO is empty, or it
wrapped exactly and is completely full. The pointers alone cannot tell you
which. `OVF_COUNTER != 0` says samples were dropped, so this is the full case,
and the code substitutes `FIFO_DEPTH`. Getting this wrong means silently reading
zero samples forever after one overflow.

**`OVF_COUNTER` is consulted _only_ for that tie, and the nesting is the whole
point.** Below `FIFO_DEPTH` unread samples nothing can have been lost, so the
pointer delta is the entire truth and the counter has no vote — which is why the
`available == 0` test is on the outside and the counter test is inside it. The
reverse nesting reads naturally and is a real bug: it treats the counter as a
standalone "samples were lost" flag. On this part that flag is non-zero in normal
operation — on the bench it tracked the available-sample count exactly, 5 per
200ms poll at 25Hz, from the first poll after a `fifo_reset()` onwards, which is
a state where a 32-deep FIFO cannot possibly have overflowed. The consequences
were a warning on every single poll, and a latent corruption: an ordinary empty
poll (`available == 0`) would be misread as full, splicing `FIFO_DEPTH` stale
entries into the window and walking the read pointer a full lap around a 5-bit
register back onto itself.

The lesson generalises past this register. **A status flag is only evidence where
the thing it reports is possible.** Cross-check it against the state that must
hold for it to mean anything — here, the pointers — rather than trusting it
on its own.

The rest is mechanical:

- `MIN(available, max_samples)` — never write past the caller's buffer. What's
  left stays in the FIFO for next time; the read pointer only advances by what
  we actually read.
- One burst read of `available × 6` bytes. Reading `FIFO_DATA` repeatedly
  auto-increments the chip's read pointer, which is why a single burst drains
  cleanly.
- Unpack:

```c
samples[i].red = sys_get_be24(&entry[0]) & ADC_COUNT_MASK;
samples[i].ir  = sys_get_be24(&entry[3]) & ADC_COUNT_MASK;
```

Each channel is 3 bytes, big-endian, but the data is only **18 bits,
right-justified**. The top 6 bits of the 24 are not meaningful, so
`ADC_COUNT_MASK` (`0x03FFFF`) clears them. Skip the mask and you get sporadic
huge values that look like motion artefacts and will waste an afternoon.

Return value is the sample count (possibly 0) or a negative errno — the standard
Zephyr convention, which is why `main()` can check `n < 0` and still use `n` as
a loop bound safely.

### 3.7 `ppg_stop()`

Puts the chip in shutdown (`SHDN`, bit 7) *then* drops the rail.

> ⚠️ **The `SHDN` write is not fire-and-forget, and the reason is the whole of
> the paragraph below.** It is the only reach the firmware has to the chip's own
> ~600µA, because that draw is on VDD and no load switch gates VDD. A write that
> failed silently would leave the part converting in SpO₂ mode through the
> entire `PAUSE` — 90 of every 121 seconds — and on every subsequent cycle too,
> with nothing anywhere saying so. **A silent ~600µA against a ~305µA budget
> (§5.1.1), undetectable in the log by construction.**
>
> So the write is retried up to three times and an outright failure is a
> `LOG_ERR` naming the current. The rail still drops unconditionally: whatever
> happened to the register write, the LEDs are the expensive half. It is the
> largest single draw in this file that firmware could otherwise lose track
> of.

Order matters slightly — telling the chip to stop before yanking its LED supply
is politer than the reverse, and the WS4622C actively discharges VLED+ once EN
drops, so the rail collapses fast.

**Why both halves are worth doing.** Dropping LED_EN alone would already kill
the expensive part, the LEDs. But `SHDN` also takes the chip's own digital and
analog draw from roughly 600µA down to ~0.7µA, and that runs on VDD — the 1.8V
rail, which no load switch gates. U3 cannot turn it off, so the register write
is the only way to reach it. Over a 52-second gap that difference is worth more
than it looks.

> This is the function that used to be written but never called. It is now on
> the hot path: `ppg_init()` ends with it, every window ends with it, and every
> `ppg_start()` failure unwinds through it.

### 3.8 `fifo_reset()`

Three writes, zeroing `FIFO_WR_PTR`, `OVF_COUNTER` and `FIFO_RD_PTR`:

```c
static const uint8_t ptrs[][2] = {
    { REG_FIFO_WR_PTR, 0x00 },
    { REG_OVF_COUNTER, 0x00 },
    { REG_FIFO_RD_PTR, 0x00 },
};
```

**Why all three and not just the pointers.** Zeroing WR and RD makes the FIFO
read as empty (§3.6: `available = (WR - RD) & 0x1F` = 0). But `OVF_COUNTER` is
the tiebreak that decides whether "empty" means *empty* or *exactly full* — leave
it stale and non-zero, and the very next poll takes the `available == 0` branch,
believes the counter, and splices 32 samples of nothing into the window. The
three registers are one state, so they get reset as one.

**Why three writes and not one burst.** They're contiguous, so a burst would work
and §3.6 does exactly that for reading. Writing them separately is a deliberate
non-optimisation: this runs once per window, 60 times an hour, and the loop with
its error check per write is easier to be sure of than a 3-byte burst whose
partial failure would leave two of the three zeroed. Read-side burst for
atomicity, write-side loop for clarity — the asymmetry is intentional.

### 3.9 The state machine `ppg.h` implies

Worth having in one place, because the ordering rules are scattered across §3.4
through §3.7 and every one of them is load-bearing:

```mermaid
stateDiagram-v2
    [*] --> Dark: power-on
    Dark --> Configured: ppg_init()
    note right of Configured
        registers loaded
        rail DOWN, SHDN set
    end note
    Configured --> Running: ppg_start()
    Running --> Configured: ppg_stop()
    Running --> Configured: any failure
    note right of Running
        rail UP, LEDs pulsing
        ~20mA. The expensive state.
    end note
```

The invariant: **`Configured` and `Dark` are indistinguishable from the battery's
point of view, and `Running` costs ~20mA.** So every path into `Running` is
`ppg_start()`, every path out is `ppg_stop()`, and there is no third way. That's
why `ppg_init()` ends by calling `ppg_stop()` on the success path (§3.4), why
`ppg_start()` unwinds through `ppg_stop()` on failure (§3.5), and why `main.c`
calls `ppg_stop()` even when `ppg_start()` *failed* (§5) — a start that got the
rail up and then failed the I2C write would otherwise leave it up forever.

**`Configured` retains everything.** That's the SHDN property (§3.5): the state
machine has no "reconfigure" edge because it doesn't need one. Registers written
once at boot are still there a minute — or a week — later.

**What `ppg.h` deliberately doesn't expose.** No "is it running" query, no
sample-rate setter, no LED-current setter. The rate is a `#define` the whole
system's timing derives from (`PPG_SAMPLE_RATE_HZ`, §3.2), not a runtime value —
if it were settable, `VITALS_WINDOW_SAMPLES` and `LAG_MIN`/`LAG_MAX` couldn't be
compile-time constants, the buffers couldn't be statically sized, and the
`BUILD_ASSERT` in §5.1 couldn't exist. Making it configurable would cost the
compile-time proof that the window can hold a beat.

---

## 3A. `imu.c` — the BMA530 accelerometer

Newest file in the tree, and deliberately the smallest thing that can prove the
part works: chip ID, health, range, output rate, data registers. No step
counter, no fall detection, no interrupts.

**Confirmed on hardware.** At rest the vector magnitude reads ~991mg against a
true 1g, which is inside the part's own tolerance plus this file's integer
truncation. That single number is the bring-up: it says the axes are being
unpacked correctly, the sign extension is right, and the sensitivity constant
matches the configured range. Everything below is what it took to get there.

### 3A.1 The part is a BMA530, not a BMA456

This section used to describe a BMA456 driver, the DTS node was called `bma456`,
and §6 confidently explained that the IMU was blocked on a `compatible`
property. All of that was wrong, and it was wrong because a part number was
taken from the devicetree instead of from the schematic.

**The v49 schematic fits a BMA530** (designator AC2, 6-ball WLCSP: `VSS`, `VDD`,
`INT1`, `INT2`, `SCL`, `SDA`). It is a different generation from the BMA456 with
an incompatible register map. The node is now `bma530`.

| | BMA456 | **BMA530** |
|---|---|---|
| `CHIP_ID` (0x00) | `0x16` | **`0xC2`** |
| Acceleration data | `0x12` | **`0x18`** |
| Data format | 12-bit left-justified in 16 | **full 16-bit two's complement** |
| Sensitivity at ±4g | 512 LSB/g | **8192 LSB/g** |
| Enable | `PWR_CTRL` bit 2 (0x7D) | **`ACC_CONF_0.sensor_ctrl` = `0xF`** (0x30) |
| Configuration | `ACC_CONF` 0x40, `ACC_RANGE` 0x41 | **`ACC_CONF_1` 0x31, `ACC_CONF_2` 0x32** |

The data-format row is the one worth dwelling on, because it is the row that
would not have failed loudly. A BMA456-shaped unpack (`>> 4`, 512 LSB/g) on
BMA530 data reads every value **16× too small** — about 62mg at rest instead of
1000. Plausible, non-zero, responsive to movement, and completely wrong. The
`|a| ≈ 1000` check above exists precisely because it catches that class of
error, where "the numbers move when I wave it" does not.

**The lesson is the one already in this document's own memory of itself:** the
schematic is the hardware authority. A devicetree node is a claim about the
hardware written by a human, and this one had been wrong since the file was
created.

### 3A.2 Why it is hand-rolled

The DTS declares the part `compatible = "i2c-device"`, which claims the address
and binds no driver (Appendix C.4). §6 used to present that as the obstacle —
change the `compatible`, get Bosch's in-tree driver. The resolution went the
other way: `imu.c` drives the part directly, exactly as `ppg.c` does for the
MAX30102, and the `i2c-device` binding turns out to be exactly right. Both
`CONFIG_SENSOR` and `CONFIG_BMA4XX` are gone from `prj.conf`.

**No load switch.** The one structural difference from `ppg.c`: the BMA530 sits
on the always-on 1.8V rail, so there is no GPIO in this file at all.
`imu_stop()` reaches the part's draw through a register write and nothing else.

**Address.** `0x18`, fixed. The 6-ball package exposes no SDO pin, so unlike the
BMA456 there is nothing to strap and nothing to get wrong.

### 3A.3 The soft reset, and two wrong conclusions about it

This cost two flash cycles and is the most transferable thing in this section.

The datasheet documents two separate un-acknowledged transactions:

1. The **initial transaction** after power-up selects the serial interface
   (I²C vs SPI 4-wire). Over I²C *"the initial transaction is not acknowledged
   by the sensor (NACK)"* and its returned value is invalid.
2. A **soft reset** (`CMD` 0x7E ← `0xB6`): *"If this register is set using I2C,
   an ACK will NOT be transmitted to the host."*

A driver that opens with a soft reset therefore cannot tell those two apart —
and worse, its reset write is liable to be consumed *as* the interface-selecting
transaction, so the reset never happens and the interface is left in an
undefined state. The observed symptom was `-ETIMEDOUT` on every subsequent
transaction, which reads exactly like an absent part.

**Removing the soft reset appeared to fix it outright**, and that conclusion was
half right and cost two more flash cycles to correct. The retry loop added at the
same time is what actually fixed it — it absorbs however many throwaway
transactions the part wants, instead of the driver having to predict the count.
**The reset is back**, and §3A.3a is why.

### 3A.3a Why the soft reset had to come back

Dropping it introduced a subtler failure that only shows up on the *second* boot.

**This driver is stateless across an SoC reset. The BMA530 is not.** A reflash or
a debugger reset restarts the nRF52 without removing the IMU's supply, so the
part keeps its configuration, its power state and its health status. Without a
reset, every boot after the first inherits whatever the previous run left —
including the disabled front end that `imu_stop()` deliberately leaves behind.

A disabled front end reports itself unhealthy. `HEALTH_STATUS` came back `0x09`
instead of `0x0F`, `imu_init()` refused, and the whole motion feature went with
it. The signature is distinctive and worth recognising: **it worked exactly once
— on the first boot after a real power cycle — and never again.** Anything that
works once and then never repeats until you unplug it is a retained-state bug.

The datasheet points at this directly. §4.7 calls the soft reset *"largely
equivalent to a power cycle… functional in all operation modes"*, and §4.8 names
it as the remedy for exactly this: *"if the value remains on error state after
reset and the external supply is stable, the device should be checked."* The
reset is the prescribed first response to a bad health status, and this driver
was skipping it.

**And health is no longer a gate.** It is polled (its reset value is `0x00`, so
reading it once immediately reads it too early) and then reported as a warning
rather than a refusal. The datasheet is right that a non-`0x0F` value means an
internal error — but returning `-EIO` on one cost the entire feature on a part
that read its chip ID correctly and produced acceleration accurate to 991mg
against a true 1g.

What decides usability instead is `imu_start()`, which now refuses unless a real
conversion actually arrives. **That is a measurement of the property we care
about rather than a proxy for it**, and unlike a status bit it cannot pass on a
dead front end.

> **The general shape.** When a datasheet says a transaction is not
> acknowledged, that is not a footnote about politeness — it means the
> transaction is indistinguishable from a failure, and anything you sequence
> behind it is built on a guess. Two documented NACKs back to back is a
> combination to take apart, not to implement literally.

### 3A.4 What the bus scan proved, and why it stays

`i2c_bus_scan()` in `main.c`'s bench mode runs only after `imu_init()` has
already failed. It was decisive: it reported `0x18`, `0x57` and `0x6a`, which
established in one line that the IMU was present and acknowledging, that the
MAX30102 was fine, and therefore that the bus, the pull-ups and the pin
assignment were all healthy. The fault had to be in the driver.

Without it, `-ETIMEDOUT` from one transaction is consistent with an absent part,
a dead part, a wrong address, a bus fault, and a driver bug, and there is no way
to choose between them from the console. **A refusal that does not say what it
saw teaches nothing** — the same argument as `Not worn (IR DC …, needs …)` in
§5.4.1 and the part-ID log in §3.4.

(`0x6a` is the BQ25180 PMIC, which firmware still never talks to — §6.)

### 3A.5 Configuration

| Register | Value | Meaning |
|---|---|---|
| `ACC_CONF_1` (0x31) | `0x25` | **LPM** (duty cycling), average-4, **50Hz** |
| `ACC_CONF_2` (0x32) | `0x0D` | −60dB IIR roll-off, **±4g** |
| `ACC_CONF_0` (0x30) | — | **not in the config table** — see below |

**`ACC_CONF_0` is conspicuously absent from the config array**, for the reason
`MODE_CONFIG` is absent from `ppg_init()`'s (§3.4): its `sensor_ctrl` field is
what enables the accelerometer, and enabling belongs to `imu_start()`.
`imu_init()` ends by calling `imu_stop()`, so the part comes out of boot
configured, verified and idle.

> ⚠️ **The accelerometer must be disabled *before* the configuration is
> written, and it is running when you first meet it.** `ACC_CONF_0` comes out of
> reset at `0x0F` — enabled — and the datasheet (§4.2.6) says configuration
> should be changed with it disabled, with changes applied immediately. Writing
> power mode, ODR and range underneath a live conversion is how the part latches
> `sensor_ctrl` to `0x0E`, *"a wrong configuration was found"*, and then refuses
> to enable.
>
> The failure surfaces a long way from its cause and looks nothing like it:
> `imu_start()` reports a rejected configuration, `imu_ready` stays false, and
> the firmware silently loses **both** the motion stream (§5B.1) and the
> movement-gated probe (§5.3.1) — so the visible symptom is "BLE motion field is
> empty *and* shaking the ring no longer wakes it", two apparently unrelated
> features failing together. `imu_init()` now writes `SENSOR_CTRL_DISABLE`
> before the config table for exactly this reason.
>
> This is the third time on this part that a *sequencing* rule, not a value, has
> been the bug — after the soft reset (§3A.3) and the interface-selecting
> transaction. The register map is easy; the order is where the BMA530 keeps its
> traps.

**Why ±4g.** ±2g resolves gentle movement twice as finely and would be better
for the movement signal alone. ±4g is chosen because a fall lands well past 2g,
and a clipped impact is indistinguishable from a lesser one — the range that
loses information is the range that loses the event this device exists to catch.
Movement still resolves to ~0.12mg.

**Why LPM, and why it is the most consequential constant in the file.** The part
now runs continuously (§3A.9), so the power mode decides whether that is
affordable. From the datasheet, at this board's 1.8V rail:

| State | Current |
|---|---|
| Suspend | 4.75µA |
| LPM @ 12.5Hz | 8.3µA |
| LPM @ 25Hz, avg4 | 10.9µA |
| **LPM @ 50Hz, avg4 — as configured** | **15.0µA** |
| LPM @ 100Hz | 18.0µA |
| **HPM, any ODR** | **125µA** |

The trap is in the datasheet's §4.2.4: *"only in LPM does the overall power
consumption depend strongly on the chosen ODR."* **HPM costs ~125µA whether it
is clocked at 50Hz or 1600Hz**, so lowering the rate in HPM saves nothing — the
*mode* is the knob, not the rate, which is the opposite of the intuition the
rest of this document builds around duty cycling.

Against the ~290µA device budget (§5.1.1) that is the difference between the IMU
costing **30%** of the battery and costing **5%** — about a day and a quarter of
the four the cell is good for. The first version of this file shipped HPM,
because it was written for a bench mode where nothing ran for long.

**Why 50Hz.** Far more than movement needs; a limb has nothing above a few Hz.
Two reasons it does not go lower: it is the rate a fall detector wants, and it
is the slowest rate at which the BMA530's step counter will run in LPM
(datasheet table 20 — LPM requires ≥50Hz). Dropping to 25Hz saves 4µA and closes
that door for the sake of ~1% of the budget.

Note that in LPM `acc_bwp` selects **how many samples are averaged**, not a
filter shape: `0x02` is "average 4", not "normal mode". Same field, different
meaning per power mode.

### 3A.6 Two checks that are not the chip ID

**Health.** `HEALTH_STATUS` (0x02) low nibble reads `0xF` when the internal
checks pass. This is a different question from the chip ID: the ID says the right
part is on the bus, the health says its analog front end came up. It is polled
after the reset and reported as a **warning, not a refusal** — see §3A.3a for why
gating on it was a mistake.

**Configuration read-back.** The BMA530 signals a rejected configuration by
*refusing to enable* — `sensor_ctrl` reads back `0xE` — rather than by failing
the write. So `imu_start()` writes the enable, waits, and reads the field back;
a write that returned 0 is not evidence the part accepted it.

### 3A.7 Data validity, and `-EAGAIN`

`0x8000` is a reserved "no valid data" pattern, returned before the first
conversion lands after a start or a configuration change. `imu_read()` detects
it and returns `-EAGAIN`.

That is deliberately not folded in with the bus errors. `-EAGAIN` means *the
part answered and has nothing yet*, which is a wait; any other negative return
is a fault. Reporting the pattern as a reading instead would put a confident
−4000mg on all three axes — the same class of error as §4.5's "a MAX30102
pointed at empty air returns a perfectly well-formed stream of small numbers".

### 3A.8 What is deliberately not here — and how cheap the step counter actually is

The BMA530's advanced features — step counter and detector, tilt, orientation,
significant motion, generic interrupts — run in its **feature engine**. None of
them is needed to read acceleration and none is implemented.

> **Correction to an earlier claim in this document.** §3A.8 previously said
> these features sit behind a configuration blob that must be uploaded at every
> boot. **That is true of the BMA456 and false of the BMA530**, and it was
> carried across with the rest of the wrong-part assumptions in §3A.1. On this
> part:
>
> - `FEAT_ENG_CONF.feat_eng_ctrl` (0x50) has **reset value 1** — the feature
>   engine is enabled out of reset.
> - There is **no configuration file, no download, no `INIT_CTRL` sequence**.
>   `FEAT_ENG_GP_FLAGS.feat_init_stat` merely reports that the engine
>   initialised itself.
>
> The step counter is therefore far closer to hand than "a real fork in the
> road" implied.

**The step count is readable from the ordinary register map.** No extended-map
access is needed to *read* it — three contiguous bytes, so one burst:

| Register | Field | |
|---|---|---|
| `0x57` `FEAT_ENG_GPR_2` | `step_cnt_out_0` | low byte |
| `0x58` `FEAT_ENG_GPR_3` | `step_cnt_out_1` | middle byte |
| `0x59` `FEAT_ENG_GPR_4` | `step_cnt_out_2` | high byte |

> ⚠️ **The datasheet contradicts itself here.** The prose in §4.9.5 names
> `FEAT_ENG_GPR_1/2/3`; the register map table and the per-register descriptions
> both say `FEAT_ENG_GPR_2/3/4` (0x57–0x59), with explicit
> *"Step counter value byte-0/1/2"* definitions. **The register map is right and
> the prose is off by one.** Following the prose reads `gen_int*_data_src` as the
> low byte of the step count and silently produces nonsense.

**Enabling it** takes two writes, because the count is produced by the feature
engine and the engine's general-purpose registers are staged. `imu_init()` now
does both:

1. `FEAT_ENG_GPR_0.step_en` — **bit 3** of `0x55`, read-modify-written so the
   other feature bits in that register (tilt, orientation, significant motion,
   the three generic interrupts) survive.
2. `FEAT_ENG_GPR_CTRL.update_gprs` — bit 0 of `0x54`, which copies the
   host-owned first-stage registers into the second stage. A GPR write that is
   never committed does nothing, and fails quietly.

The finer configuration (`sc_en`, `sd_en`, `reset_counter`, `watermark_level`)
lives in the extended register `STEP_COUNTER` at extended address `0x19`, reached
through `FEATURE_DATA_ADDR`/`FEATURE_DATA_TX` — but its **reset value is
`0x1800`, which already has `sc_en` and `sd_en` set**, so a minimal
implementation needs no extended access at all.

Two behaviours worth knowing before trusting the number:

- **`watermark_level` carries an implicit ×20 scaling**, and steps are buffered
  internally, so a watermark interrupt lands somewhere between 200 and 210 steps
  rather than exactly on the boundary.
- **`reset_counter` self-clears.** Write 1, counting restarts, and the bit
  returns to 0 on its own.

**The ODR requirement is already met.** The step counter needs HPM at any rate or
**LPM at ≥ 50Hz** (datasheet table 20), and §3A.5 sits at LPM 50Hz — chosen partly
for this reason. Bosch quotes no separate current adder for the feature engine,
so the count is very close to free on top of the 15µA already being spent.

**Implemented as of `imu_read_steps()`.** The running total goes out on the
motion characteristic (§5B.1); a per-record **delta** is now also stored in
flash, since the record widened (§5A.3). The two forms are deliberate — a lost
packet costs a live consumer nothing when it carries a total, while a log that
gets flushed and erased has no earlier record to difference against, so the
subtraction happens in `main.c` while both totals are still in hand. Nothing in
the firmware *acts* on the count; it is stored so that anything adapting to
what the wearer is doing has the history it needs.

**What it buys** is the biggest argument for the accelerometer: **120bpm from
climbing stairs and 120bpm at rest are currently the same number**, and steps in
the last minute separate them directly. Activity context is what turns a rate
into something a consumer of the log can interpret, and it needs no impact
detection at all.

The remaining genuine fork is **wake-on-motion**: the significant-motion or
generic interrupt could drive the measurement cadence instead of the timer in
§5.3.1, and `imu_int_pin` (P0.18) is already wired to INT1. That one needs
interrupt handling this firmware does not yet have anywhere (§6).

### 3A.9 How the real firmware uses it

`imu_init()` and `imu_start()` run once at boot, beside the battery monitor and
the flash log, and the accelerometer then **stays on for the whole session**.
There is no `imu_stop()` on the cycle path.

That is a deliberate break from how `ppg.c` is treated, and the arithmetic above
is the whole reason: at 15µA the bookkeeping to duty-cycle the IMU would cost
more in complexity than it could ever return in current, where the MAX30102's
LEDs and its own ~600µA supply make duty cycling the entire game (§5.1). It is
also the precondition for any future wake-on-motion path — a part that is off
cannot raise an interrupt.

**Failure is non-fatal**, the same posture as `battery.c`, `flash_store.c` and
`ble.c`: `imu_ready` gates the reads, `main()` logs `IMU unavailable, continuing
without motion data` and carries on. Only `ppg_init()` failing returns from
`main()` — no pulse means the device has no reason to exist; no motion means a
degraded one.

**It has two jobs, and the second one is not about measuring at all.** Besides
the per-package reading below, the accelerometer is what decides when to look
for a finger again after the ring comes off (§5.3.1) — movement gates the probe,
so a still ring costs nothing and a ring being picked up is noticed in a quarter
of a second. That job is only possible because the part is left running, and it
is the closest thing the firmware currently has to wake-on-motion.

**One reading per package**, taken in `record_one()` (§5.5.2) and stamped with
the *same* timestamp as the vitals package it accompanies. That alignment is the
point rather than a convenience: the reason this device has an accelerometer is
to give a heart rate context, and context that cannot be lined up with the
reading it explains is worth much less. The acceleration itself is notified over
BLE (§5B.1) and **still not stored** — three axes per record is a lot of flash
for a number whose useful summary is "was the wearer moving", and the step delta
that the widened record does carry (§5A.3) answers that far more cheaply.

---

## 4. `vitals.c`

Raw counts in, a heart rate and an SpO₂ out. This file is pure arithmetic — no
I2C, no GPIO, no hardware at all — which is deliberate: it means the whole thing
can be compiled on a laptop and fed synthetic waveforms with known answers. It
was, and that testing found two real bugs before the code ever reached the ring
(§4.3). Keep it that way.

### 4.1 The window

Vitals cannot be computed from a sample; they need a stretch of signal long
enough to contain several beats. `VITALS_WINDOW_SEC` is 15, which at 25Hz is 375
samples — 10 beats at the slowest rate we accept and ~50 at the fastest.

**Why 15 and not less.** The window is the whole of the latency: on the sliding
window §5.2 uses, a reported rate lags a real change by most of a window, so
shorter is genuinely better right up until it isn't. Measured against the
45–200bpm sweep on a weak, drifting signal — 0.2% perfusion, the ring's worst
realistic case — the number of windows coming back more than 5bpm wrong is:

| Window | 8s | 10s | 12s | **15s** | 20s | 30s |
|---|---|---|---|---|---|---|
| windows >5bpm wrong (of 63) | 9 | 4 | 5 | **0** | 0 | 0 |
| …still wrong above `BPM_CONFIDENCE_MIN` | 6 | 4 | 4 | **0** | 0 | 0 |
| SpO₂ bias, ring-grade pulse | −0.32% | −0.32% | −0.21% | **−0.11%** | +0.01% | −0.01% |

The second row is the one that decides it. Below 15s the failures are not
low-confidence — they arrive *confident and wrong*, so no gate in §4.5 catches
them, which is the one failure mode this file is built to avoid. On a good
signal 8s is fine; the table is about the bad ones.

**Why not more.** Nothing in the sweep improves past 15s, and every second added
is a second of lag. 30s (which this was, briefly) bought no accuracy and doubled
the time to a trustworthy number.

That buffer is 3KB and lives in `main.c` as a `static`, not on the stack —
`CONFIG_MAIN_STACK_SIZE` is 2048, so a local would blow it. `vitals.c` keeps
another 4.5KB of static working buffers for the same reason: two filtered
channels and one scratch, 375 `int32_t` each.

**`VITALS_MIN_SAMPLES` is half a window**, not a fixed count: `VITALS_WINDOW_SAMPLES / 2`
= 187 samples, 7.5 seconds. Below that `vitals_compute()` returns `-ENODATA`
without looking at the data. Deriving it from the window rather than pinning it
at a number keeps the two in step — shortening the window can't silently leave a
floor behind that no longer bears any relation to it — and `BUILD_ASSERT(VITALS_MIN_SAMPLES >= 2 * LAG_MAX)`
is what makes "half a window still holds two of the slowest beats" a compile-time
fact rather than a hope.

### 4.2 Getting the signal out of the noise

A raw PPG trace is mostly *not* heartbeat. In descending order of amplitude it's
a huge DC offset (light that came back regardless), slow baseline wander from
breathing and movement, then — somewhere down at **under 1% of the DC level** —
the pulse. The whole job is to find that 1%.

```
  DC removal    →  subtract the window mean
  highpass ×3   →  subtract a centred moving average, three times
  smooth3       →  3-tap boxcar
```

**Why DC removal isn't enough.** Subtracting the mean flattens the trace but
leaves the wander, and the wander is *bigger than the pulse.* This is not a
subtle effect — with a realistic breathing component the first version of this
code returned 250bpm for every input, because the autocorrelation locked onto
the drift instead of the heart.

**The high-pass.** Subtracting a centred moving average is a zero-phase
high-pass, and the trick is choosing its length: `LAG_MAX`, the period of the
*slowest heartbeat we accept.* That makes the filter's argument self-evident —
anything slower than the slowest possible beat is, by definition, not a beat.
Zero-phase matters because the phase shift of an ordinary IIR would smear the
period we're about to measure.

**Why three passes.** One pass leaves ~20% of the drift, which is still several
times the pulse. Each pass squares what's left. Three is not two because the
third measurably halves the SpO₂ bias in §4.4 and costs nothing at the slow end
(40bpm still comes back exact). It is not four because the returns had flattened.

**What the ends of the window do, which is the part that bit.** A centred
average needs `half` samples either side, and at the first and last `half`
samples of the window they don't exist. Averaging over whatever fits — the
obvious thing, and what this did originally — takes the mean of a shorter,
off-centre stretch, which on a sloped signal is just the wrong number. The error
is the size of the *drift*, not the size of the pulse, and every pass smears it
another `half` samples inward, so three passes leave ~54 contaminated samples at
each end carrying an artefact several times the heartbeat. Being slow and
end-weighted, it correlates over long lags: it puts a broad hump at the far end
of the lag band and §4.3 locks onto that instead of the pulse.

Measured on a 0.2%-perfusion window with 3% baseline wander, it took the
post-filter RMS from 26 counts (the pulse alone) to 55, and the reported rate to
*exactly half* the true one across most of the band — the same signature as the
octave bug in §4.3, from an unrelated cause. The fix is to extend the window by
**odd reflection** (`v[-k] = 2·v[0] − v[k]`) instead of shrinking the average.
Odd reflection continues the local trend rather than folding it back, so the
average of a locally straight signal stays on the trend and the ends come out as
clean as the middle; an even reflection would put a corner at each endpoint and
leave half the artefact behind. The same change let the average be carried as a
running sum, which made the filter O(n) instead of O(n·width).

**Why `BPM_MIN` is 30, and why it used to be 40.** For a long time the floor was
40 on the following reasoning: breathing sits around 0.25Hz, 30bpm is 0.5Hz, one
octave apart is not enough for a boxcar filter to separate, so a 30bpm floor
would mean passing breathing through and calling it a pulse.

That reasoning was **right about the filter and wrong about the band.** The two
had been welded together only because the filter's width was computed from
`LAG_MAX` — the longest lag the correlator searched. One number was doing two
jobs: *how slow a pulse are we willing to look for* and *how slow a wander are we
willing to pass*.

Separating them (`VITALS_HP_CORNER_BPM`, still 40) is what made a lower floor
possible. The correlator now searches down to 30bpm while the filter goes on
rejecting breathing exactly as hard as it did before. The slowest rates are
attenuated by a corner above them, and that is fine: autocorrelation measures
*periodicity*, not amplitude. A build assert enforces that the corner never
drops below the floor, because a corner *under* the floor would be pure loss —
breathing passed through for no gain in range.

**Both channels get identical filtering.** Not for tidiness — §4.4 divides one
channel's amplitude by the other's, and any gain the filters apply only cancels
if it's the same gain.

### 4.3 `estimate_bpm()` — autocorrelation, and two bugs it took to get right

**Why autocorrelation instead of counting peaks.** Peak detection needs a
threshold, and a threshold is a cliff: signal slightly too weak and you find no
beats, baseline slightly high and you find twice as many. Autocorrelation asks a
different question — *at what shift does this signal most resemble itself?* —
which is the period, which is all we want. It degrades into vagueness rather
than into confident nonsense, and it hands us a quality number for free.

```
  for each lag in 6..37 samples          (220bpm down to 40bpm)
      correlate the window with itself shifted by lag
  the winning lag is the beat period
```

**Bug one: the normalisation.** Dividing each lag's correlation by its overlap
`(n - lag)` looks obviously right — long lags overlap less, so why penalise
them? Because that decay is load-bearing. Autocorrelation peaks at *every*
multiple of the true period, and what keeps the peak at `T` taller than the one
at `2T` is precisely the decay that normalising removes. With it removed, every
rate above 90bpm came back **exactly halved** — 90→44, 100→50, 120→60. The fix
is to divide by `n` instead, and the comment in the code exists so nobody
helpfully "fixes" it back.

The line that does it divides by the signal's total energy rather than by `n`
literally:

```c
corr[lag] = (int32_t)(sum * 1000 / energy);
```

That is the same quantity — `(sum/n) / (energy/n)` — expressed as one division
instead of three, and it is worth understanding why the arrangement matters. The
form it replaced truncated twice, and each truncation threw away up to a whole
count. On a weak pulse, where the energy per sample is small, those two lost
counts were a large fraction of the correlation value, so the whole curve came
out quantised into steps — and the parabolic interpolation below, which reads
differences between adjacent points, was fitting a staircase. Scaling by 1000 up
front puts the result on a 0–1000 scale that is also exactly what `confidence`
reports, so the same number serves both purposes.

`energy` is accumulated first, and doubles as the "is there anything here at
all" test: below one count of RMS across the window (`energy < n`) the function
returns 0 rather than correlating noise.

**Bug two, and the real guard: octave error.** Dividing by `n` alone wasn't
enough. The reliable rule is to stop trusting the *tallest* peak and take the
**first competitive one** — walk up from the shortest lag and accept the first
local maximum within 80% of the best. If `T` and `2T` are both peaks, `T` comes
first and wins. Across 396 synthetic windows this took wrong-but-reported
readings from 132 to **zero**; the cases it can't solve come back as low
confidence and get refused instead — *with the confidence gate restored*, which
it currently isn't. See the warning below.

**Parabolic interpolation, and why it's what makes 25Hz affordable.** The
winning lag is an integer, so the rate lands on a grid: `1500/lag` bpm, which is
2.4bpm wide at rest and ~27bpm wide up at 200. That's the resolution the halved
sample rate gave away. Fitting a parabola through the winning correlation and
its two neighbours puts the peak back between the samples, and measured against
synthetic signals the estimate lands within 1–2bpm from 45 to 200. **Eight lines
of arithmetic bought back what would otherwise have cost double the LED current.**

The `denom < 0` check and the ±½-sample clamp are not decoration. A flat peak
gives a near-zero denominator, and dividing by it sent the estimate to absurd
lags — that's the second bug the host tests caught.

**Confidence** is just the winning correlation, 0–1000: how much the signal
actually looks like itself one beat later. Note it's `corr[chosen]`, not `best` —
it reports how good the peak we *took* was, not the tallest one in the band, so
a confident octave-guard override doesn't get flattered by the peak it rejected.

**Bug three, and the worst of them: the clamp.** For most of this project the
function ended in one line:

```c
return CLAMP(rate, BPM_MIN, BPM_MAX);
```

which promised that whatever the correlator found, the answer would land inside
the band of rates we are willing to believe. It kept that promise by **moving**
answers rather than rejecting them — and a moved answer is indistinguishable
downstream from a measured one. Same field, same confidence, no mark on it. Two
things fell out of that, both measured in `tests/host`, and both are bradycardia
hiding in plain sight:

- **A true 25bpm pulse reported a confident 50bpm** (28 reported 55). Its period
  is 60 samples and the band stopped at 50, so the correlator never saw the
  fundamental and locked onto the second harmonic instead.
- **Breathing with no pulse in it at all reported a confident 220bpm**, in 27 of
  54 windows. The correlation simply falls away from the short-lag end of the
  band, so the tallest point *in* the band is its edge — 250bpm — and the clamp
  filed it as 220.

The second is embarrassing; the first is dangerous. A rate the ring cannot see
is a gap in the record, and a gap is visible. A rate the ring reports as an
ordinary 50 is not a gap, and nothing downstream has any way to know.

So there is no clamping now. An estimate outside the band means *we do not know
the rate*, and two checks replace it:

1. **A peak on the edge of the band is not a peak.** If the correlation is still
   climbing where the band stops, whatever it climbs toward is outside — and
   which edge it is tells us which side.
2. **A sub-harmonic guard.** For an interior peak whose octave lands at or past
   the end of the band, three lags one octave down are checked. A clearly taller
   peak there means the pulse we picked is only its second harmonic and the real
   rate is below the floor.

The guard works because of the normalisation choice above: dividing by `n` rather
than by the shrinking overlap makes a genuine period's peaks *decay* at each
multiple, so a taller peak an octave down cannot be a multiple of the rate we
picked — it has to be the rate itself. Measured across the whole sweep, the
ratio `corr[2L]/corr[L]` averages ~1.3 when the fundamental is out of band and
~0.9 when it isn't. The tails overlap, because on a 0.15% perfusion window the
"pulse" is barely above the converter noise, so the threshold (1.10) is not a
clean split and cannot be — it is a choice about which way to be wrong. A false
refusal is one window of a 15-second cadence, which the next window usually
undoes. A miss is a bradycardic wearer filed as healthy for as long as it lasts.

**And "too slow" is now a finding, not a silence.** When the guard fires,
`vitals.c` sets `bpm_below_floor` and reports the sub-harmonic's confidence — the
periodicity it is declining to name a rate for. `main.c` stores that as
`FLASH_REFUSAL_TOO_SLOW`, the one refusal reason that is a statement about the
wearer rather than about the measurement.

**Where the confidence threshold lives, and why it isn't here.** There is
deliberately no heart-rate confidence gate in this file. The threshold is
`VITALS_BPM_CONFIDENCE_MIN` in `vitals.h`, and `main.c` applies it (§5.5.2). The
reasoning in the header is sound and worth stating in full, because it is a real
architectural position rather than a workaround:

> `vitals.c` can say how much a window looked like itself one beat later. Only
> the caller knows what it is about to *do* with the answer.

Zeroing `bpm` inside `vitals.c` destroys information the caller might legitimately
want — a low-confidence rate is exactly what you need to see when you are tuning
thresholds against real optics, and once it is zeroed nothing downstream can tell
"no pulse" from "a pulse I didn't trust". Reporting the rate and the confidence
separately, and letting each consumer decide, is strictly more expressive.

The threshold itself is measured rather than guessed — but measured **on the
synthetic waveforms of §0.2, not on a finger**. Windows carrying a pulse sit at
**525–960** even when the pulse is weak and drifting at ring-grade perfusion,
while windows with no pulse in them at all — empty air, motion artefacts — top
out around **360**. 500 sits in that gap. What that establishes is that the
confidence metric *separates* pulse from no-pulse; whether 500 falls in the same
place against this ring's optics is exactly the open question §0.2 raises.

> ⚠️ **Only some of the consumers used it.** `main.c` refused a rate below
> `VITALS_BPM_CONFIDENCE_MIN` — but it did that *after* `flash_store_append()`
> and `ble_notify_vitals()` had already run. **The stored log and the BLE notification therefore carry
> rates at any confidence,** including the octave errors §4.3 says come back as
> low confidence.
>
> That is a narrower problem than the gate being absent outright, but a rate in
> the log is a rate a reader will believe, and a rate on a phone is
> one a user will. Moving the two calls below the confidence check, or storing
> the confidence alongside the package (§0.3), closes it. See §5.5.2 and §6.
>
> **SpO₂ is unaffected** — `SPO2_CONFIDENCE_MIN` (600) is enforced inside
> `vitals.c` and is stricter than the HR threshold.

### 4.4 SpO₂ — ratio of ratios

Oxygenated and deoxygenated blood absorb red and infrared light differently.
That's the entire principle: measure how much each channel pulses, relative to
its own DC level, and the ratio of those two ratios tracks saturation.

```
R = (AC_red / DC_red) / (AC_ir / DC_ir)
SpO₂ = -45.06·R² + 30.354·R + 94.845
```

**Where `AC_red/AC_ir` comes from, and why not RMS.** The obvious move is RMS of
each channel. It's also wrong, and the host tests said so: SpO₂ came back a
systematic ~1% low, worse on dim optics. The reason is that the two channels'
noise is *independent* — separate LED pulses, separate conversions — so RMS
folds each channel's noise into its own AC term, inflating both. The smaller
term (red) inflates proportionally more, which pushes R up and SpO₂ down.

So instead: both channels carry the same pulse *shape*, so `red ≈ α · ir`, and
α is a least-squares projection of red onto IR — `Σ(red·ir) / Σ(ir·ir)`. α *is*
the amplitude ratio, and independent noise cancels in the cross term rather than
accumulating. That change alone cut the error from ~0.9% to ~0.3% and collapsed
the spread across bright/dim optics from 1.1% to 0.1%. It also removed a square
root from the path.

**The residual bias, measured not guessed.** What the high-pass leaves behind is
common to both channels (it scales with each one's DC), so it correlates exactly
the way a pulse does and the projection cannot tell them apart. It pulls R toward
1.0, which reads as *low* saturation. The weaker the pulse, the more the residue
dominates:

| Perfusion (AC/DC) | SpO₂ bias, before | after | Reported? |
|---|---|---|---|
| 1.1% | −0.05% | 0.00% | yes |
| 0.8% | −0.19% | −0.01% | yes |
| 0.6% | −0.45% | 0.00% | yes |
| 0.4% | −1.0% | −0.01% | yes |
| 0.25% | −2.2% | +0.03% | yes |
| 0.15% | — | −0.30% | yes |
| 0.10% | — | −0.50% | **no** |
| 0.05% | — | −0.70% | **no** |

The "before" column is the same sweep with the high-pass **edge artefact** of
§4.2 left in, and it is almost entirely a measurement of that artefact rather
than of the filter's frequency response — the residue really is common to both
channels and really does pull R toward 1.0, but it comes from the window's ends,
not from the signal. With the edges handled the bias is flat to ~0.0% down to
five times lower perfusion, and only turns over below 0.15%.

`SPO2_PERFUSION_MIN` is therefore 0.12% and not 0.5%. That is the lowest setting
at which every window in the sweep stayed inside the same half a point the old
threshold was chosen for; the ones that creep past below it are the windows
whose "perfusion" is mostly noise. The bias is one-directional and toward false
alarm, which is the safer way to be wrong, but it's still a reason to gate
rather than to shrug.

**Why this is the difference between an SpO₂ and no SpO₂ at all.** A ring is not
a fingertip clip and sees a small fraction of the perfusion one does. At 0.5%
the gate rejected essentially every real window, and since the failure is silent
— the field simply stays 0, which §4.6 initialises it to — the symptom was not
"SpO₂ is inaccurate" but "SpO₂ is never reported." Note the gate is evaluated in
parts per *ten* thousand: at ring signal levels `perfusion_milli` quantises to 0,
1 or 2, which is too coarse to put a threshold on.

> ⚠️ **The SpO₂ number is not calibrated.** Those coefficients are Maxim's
> empirical fit for *their* reference design's optical geometry — their LED
> spacing, their photodiode, their glass. This ring is none of those things. The
> arithmetic is right and the ratio is sound, but mapping R to a saturation
> percentage is a per-hardware calibration against a reference oximeter, and it
> has not been done. Treat the output as a trend, not a vital sign, until it is.
> See §6.
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

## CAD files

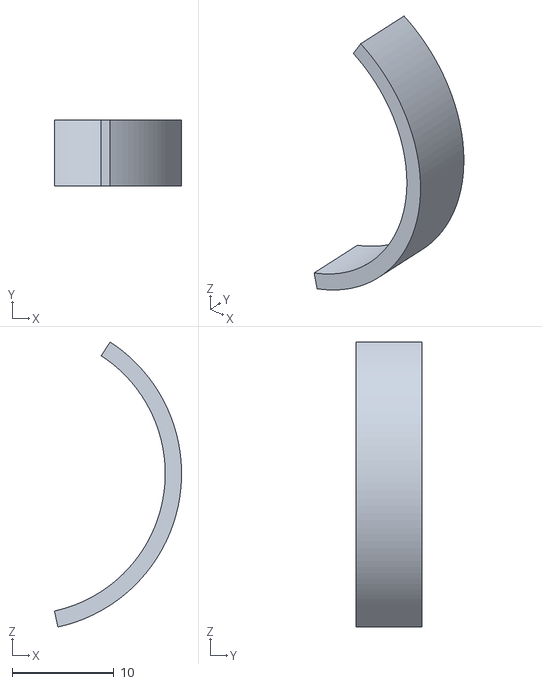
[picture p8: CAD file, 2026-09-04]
Mechanical/Battery.stl
12.5 x 6.52 x 28.0

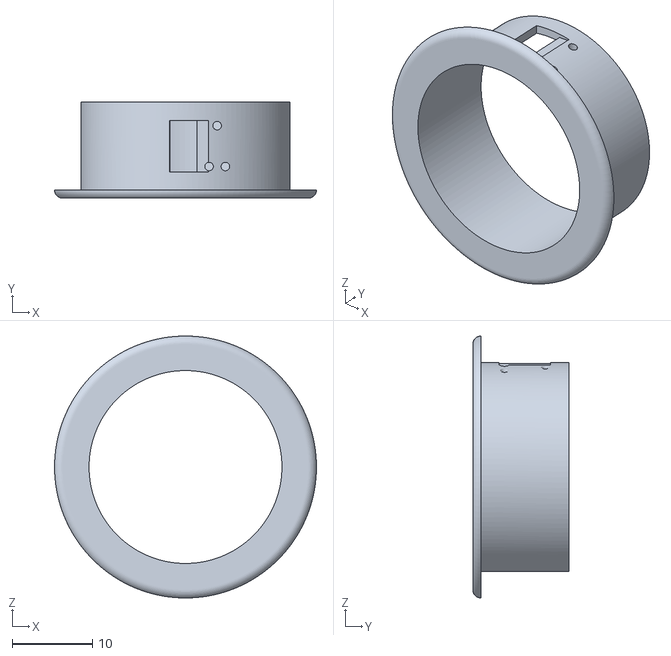
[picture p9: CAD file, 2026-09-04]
Mechanical/InnerShell.stl
32.6 x 12.0 x 32.6

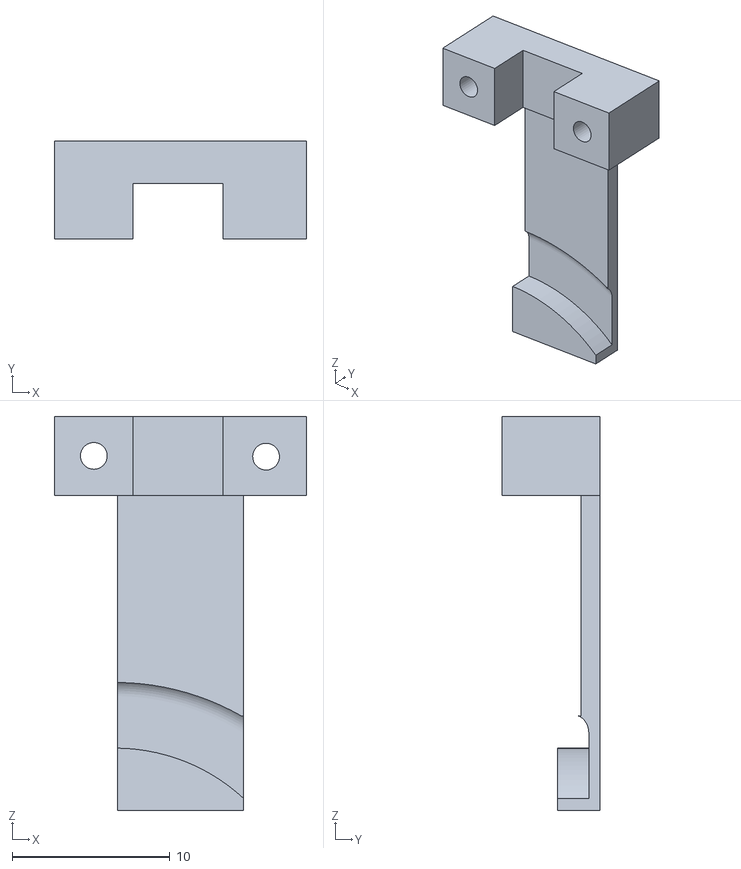
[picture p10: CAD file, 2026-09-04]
Mechanical/ProgrammerFixture1.stl
16.0 x 6.20 x 25.0

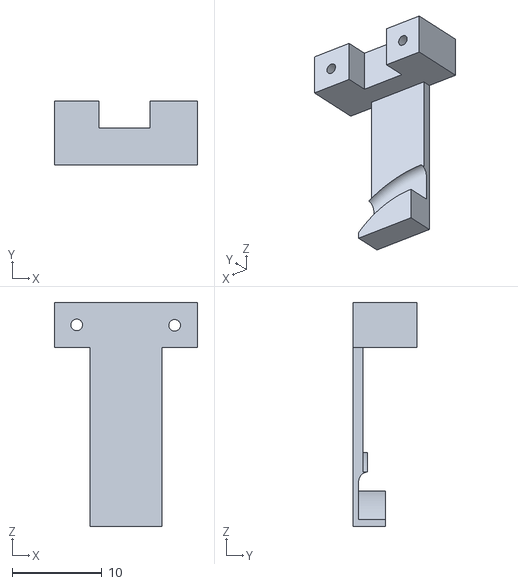
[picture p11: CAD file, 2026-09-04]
Mechanical/ProgrammerFixture2.stl
16.0 x 7.10 x 25.0

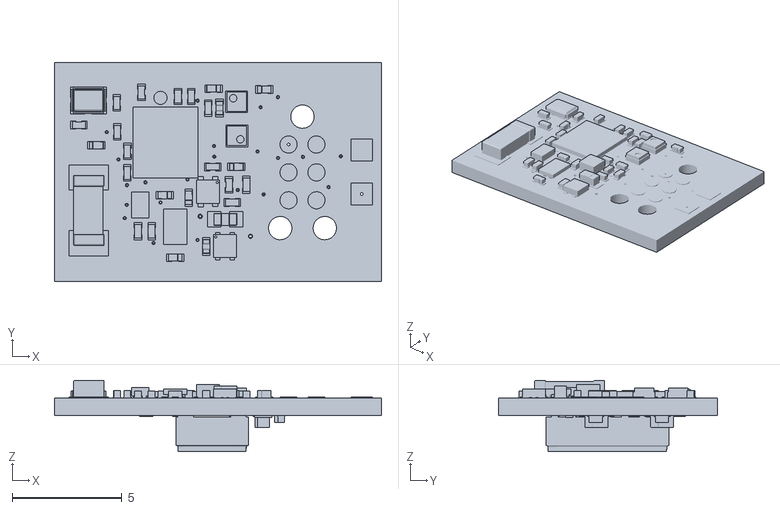
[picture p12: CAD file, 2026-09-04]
Mechanical/Board.stl
14.9 x 10.0 x 3.25

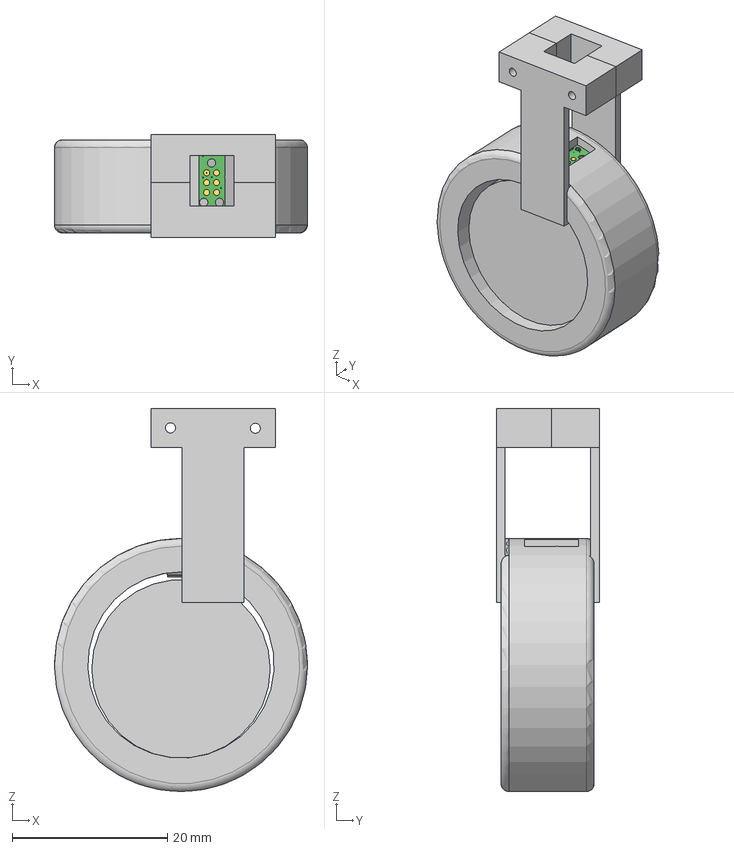
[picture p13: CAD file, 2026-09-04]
Mechanical/RingCase.step
32.6 x 13.3 x 49.3 mm
Board
1-copper
64-copper
1-soldermask
64-soldermask
MAX30102EFDT
BMA530
ANTC3216X140N
C0201 (2) x 7
C0201 x 7
L0201
416F32022CKR v1
NRF52832-CIAA-R--3DModel-STEP-56544 (1) v1
BQ25180YBGR v1
GrepowBattery

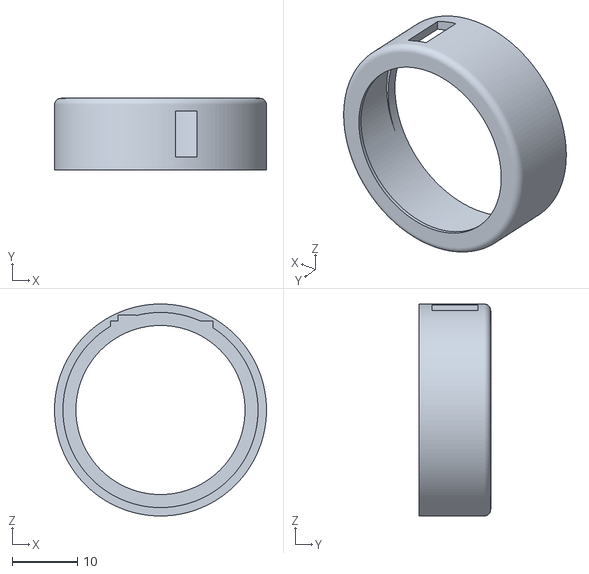
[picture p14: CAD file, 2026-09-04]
Mechanical/OuterShell.stl
32.6 x 11.0 x 32.6

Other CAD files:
Mechanical/RingCase.f3z

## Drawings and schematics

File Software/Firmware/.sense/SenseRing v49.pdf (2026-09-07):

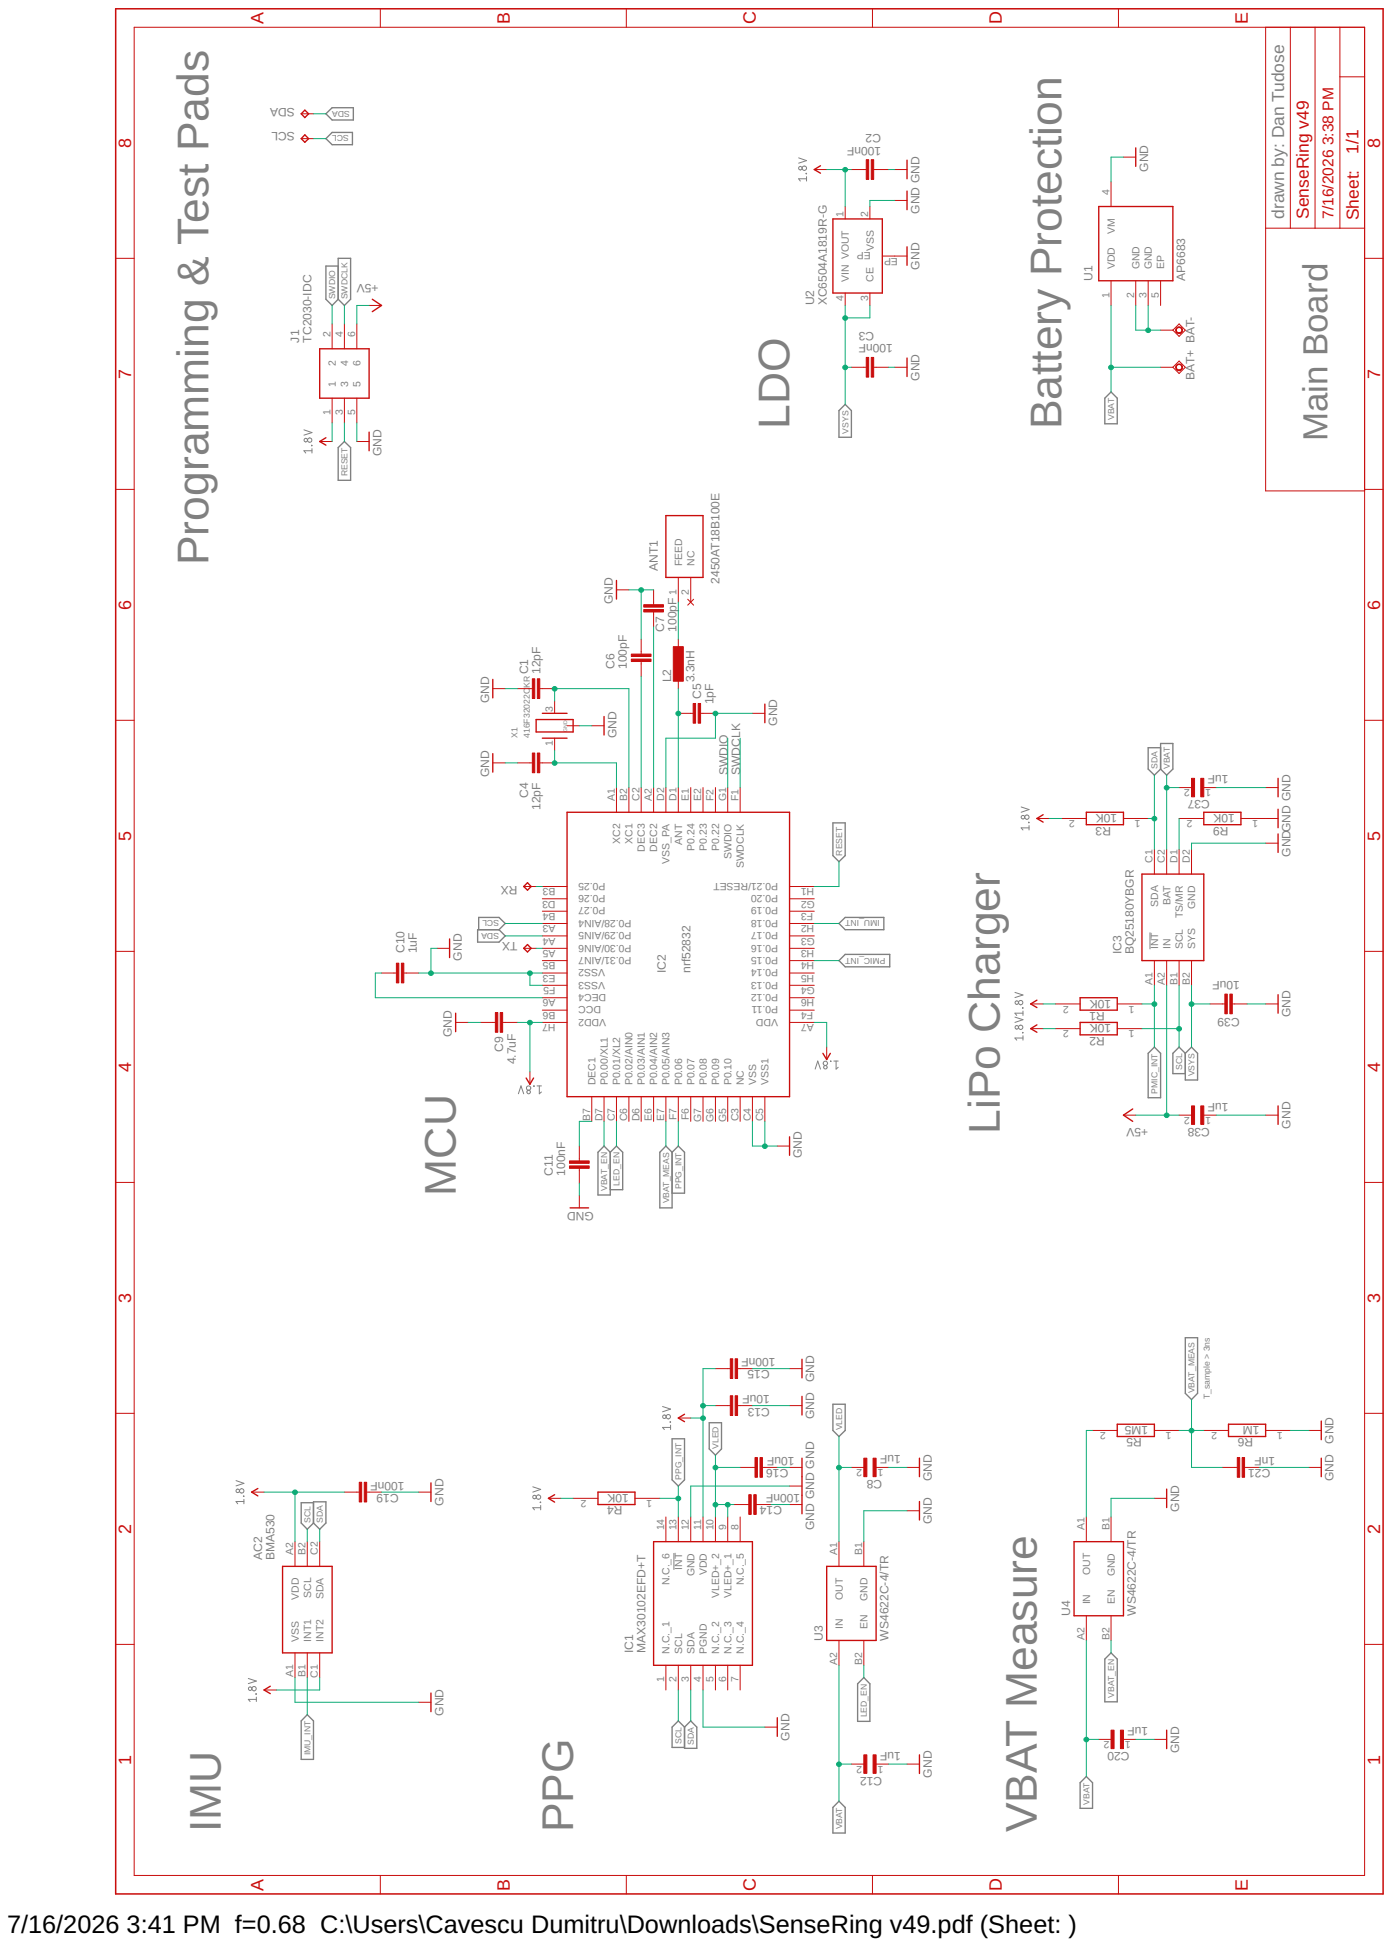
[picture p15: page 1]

drawn by: Dan Tudose

GND GND

B2 SDA C1 BAT C2 TS/MR

7/16/2026 3:41 PM f=0.68 C:\Users\Cavescu Dumitru\Downloads\SenseRing v49.pdf (Sheet: )

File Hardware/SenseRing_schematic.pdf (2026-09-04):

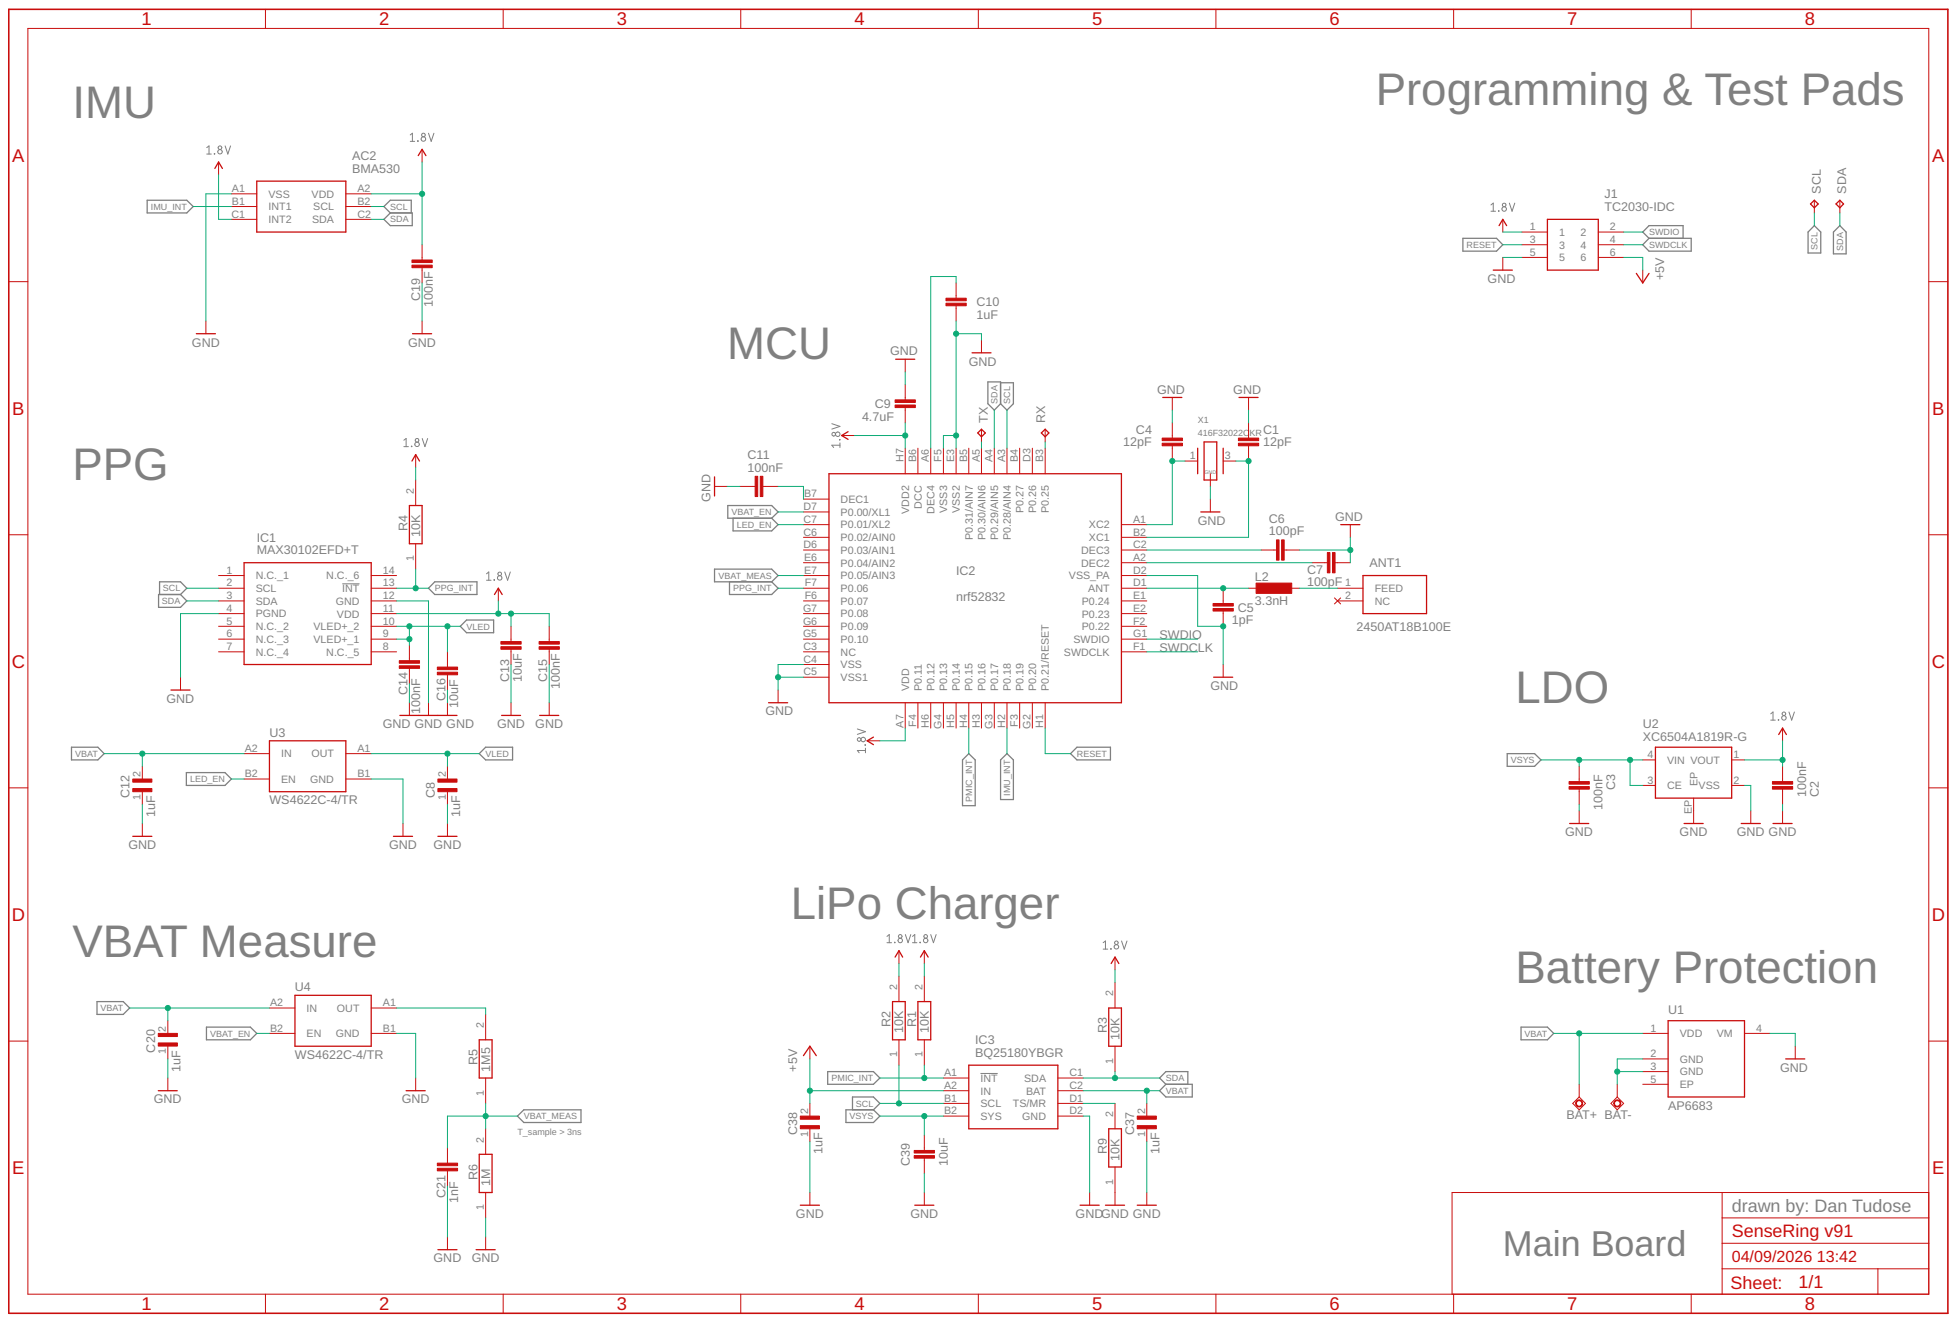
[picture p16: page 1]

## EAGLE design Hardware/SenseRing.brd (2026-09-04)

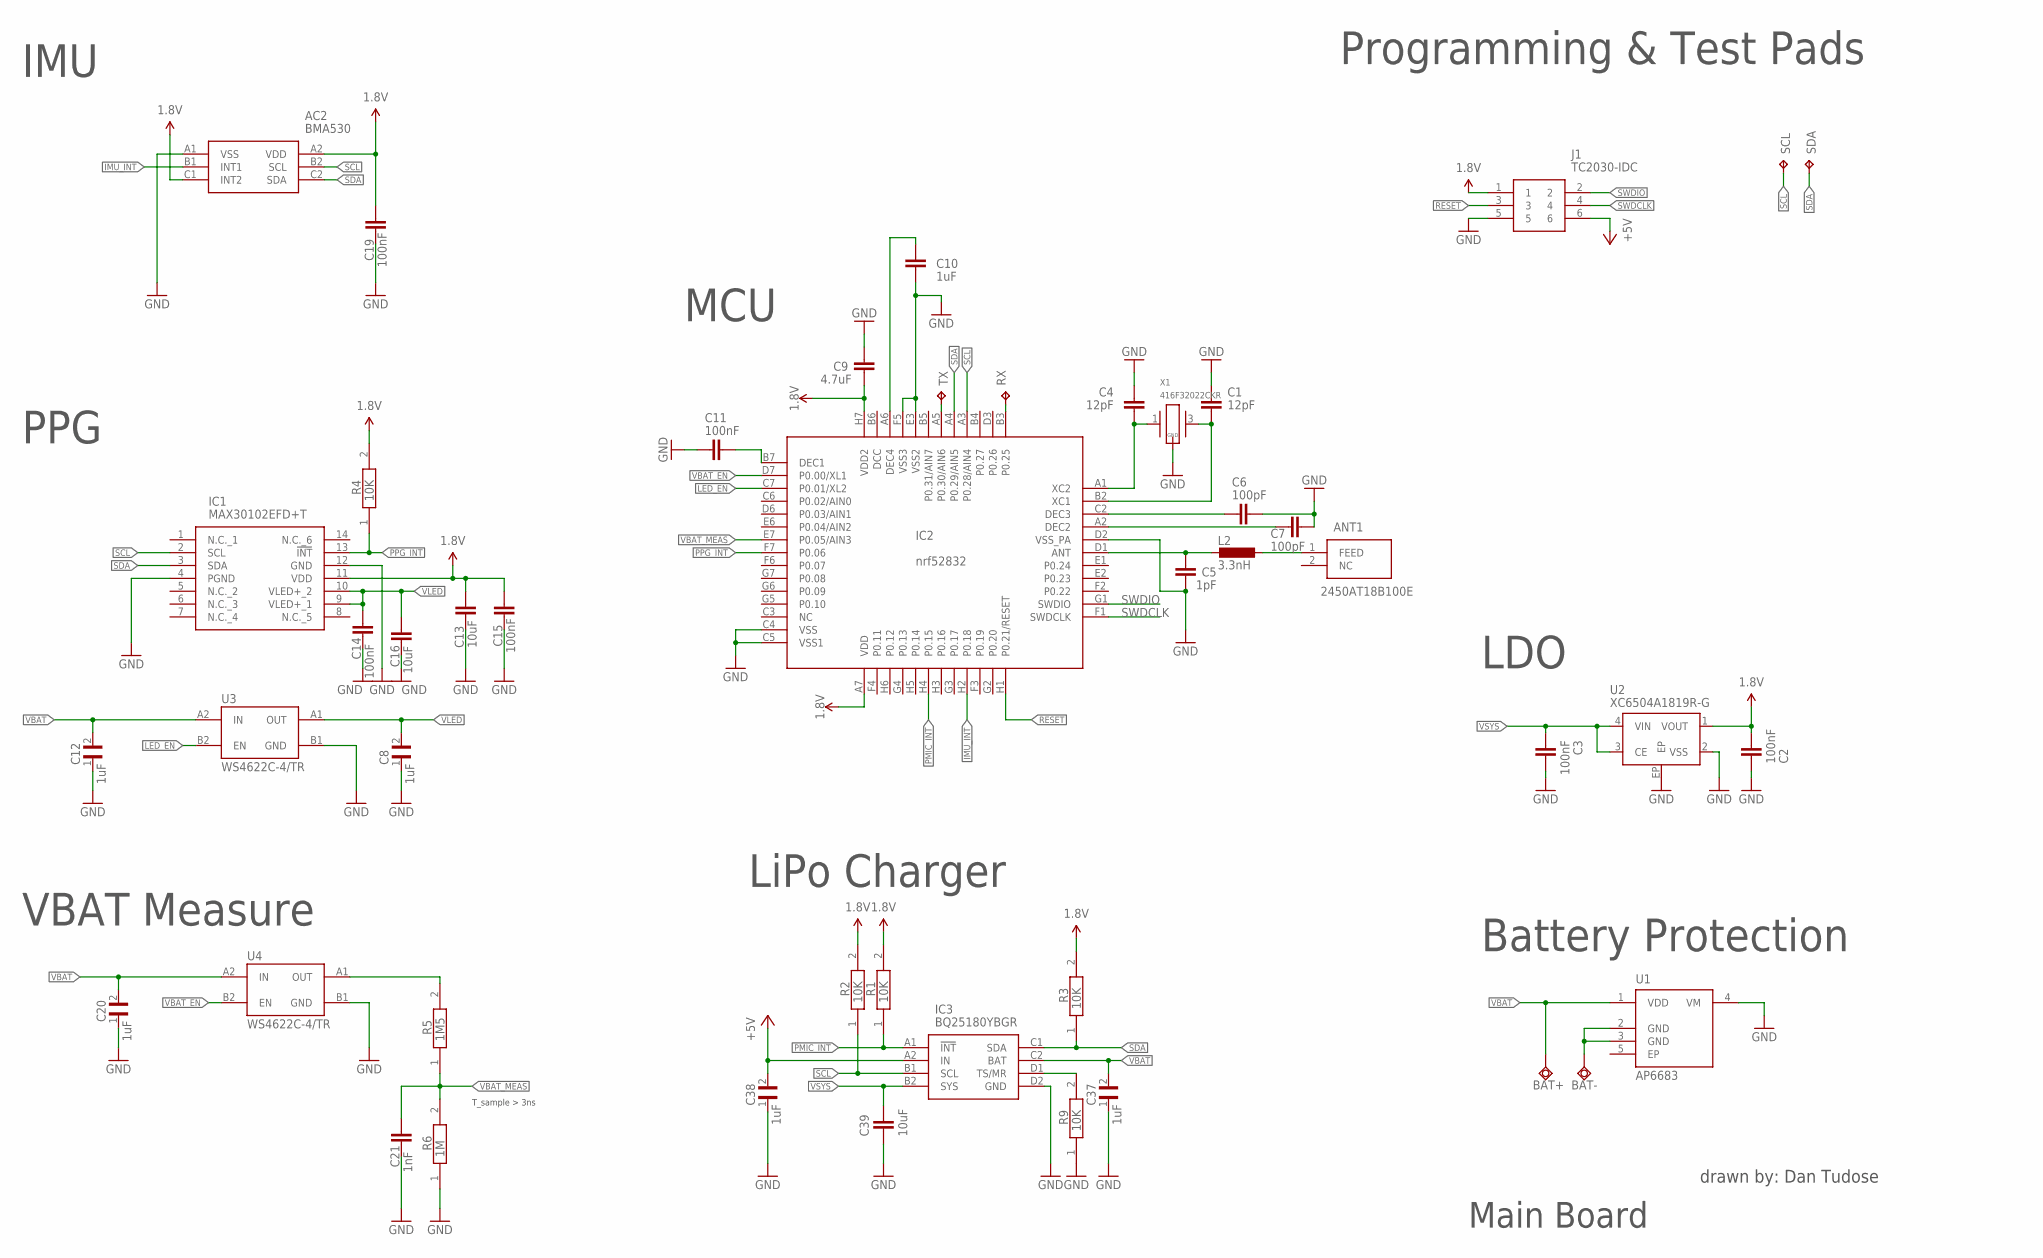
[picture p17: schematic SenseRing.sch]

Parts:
AC2: BMA530
ANT1: 2450AT18B100E; ANTC3216X140N
BAT+: TPSQTP10SQ; TP10SQ
BAT-: TPSQTP10SQ; TP10SQ
C1, C4: 12pF; C0201
C2, C3, C11, C14, C15, C19: 100nF; C0201
C5: 1pF; C0201
C6, C7: 100pF; C0201
C8, C12, C20, C37, C38: 1uF; 0201
C9: 4.7uF; C0201
C10: 1uF; C0201
C13, C16, C39: 10uF; 0402
C21: 1nF; C0201
IC1: MAX30102EFD+T; MAX30102EFDT
IC2: nrf52832; NRF52832_WLCSP
IC3: BQ25180YBGR; BGA8C40P2X4_100X155X50
J1: TC2030-IDC; TC2030IDC
L2: 3.3nH; L0201
R1, R2, R3, R4, R9: 10K; 0201
R5: 1M5; 0201
R6: 1M; 0201
RX: TPTP06R; TP06R
SCL: TPTP06R; TP06R
SDA: TPTP06R; TP06R
TX: TPTP06R; TP06R
U1: AP6683; DFN-4_L1.0-W1.0-P0.65-BL-EP
U2: XC6504A1819R-G; USPQ-4B04
U3, U4: WS4622C-4/TR; CSP-4L_1X1
X1: 416F32022CKR; M416

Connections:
1.8V: AC2.A2 (VDD), AC2.C1 (INT2), C2.1, C9.2, C13.1, C15.2, C19.2, IC1.11 (VDD), IC2.A7 (VDD), IC2.H7 (VDD2), J1.1, R1.2, R2.2, R3.2, R4.2, U2.1 (VOUT)
+5V: C38.2, IC3.A2 (IN), J1.6
GND: AC2.A1 (VSS), C1.1, C2.2, C3.1, C4.1, C5.2, C6.2, C7.2, C8.1, C9.1, C10.2, C11.2, C12.1, C13.2, C14.1, C15.1, C16.2, C19.1, C20.1, C21.1, C37.1, C38.1, C39.2, IC1.4 (PGND), IC1.12 (GND), IC2.C4 (VSS), IC2.C5 (VSS1), IC2.D2 (VSS_PA), IC2.E3 (VSS2), IC2.F5 (VSS3), IC3.D2 (GND), J1.5, R6.1, R9.1, U1.4 (VM), U2.2 (VSS), U2.EP, U3.B1 (GND), U4.B1 (GND), X1.2 (GND), X1.4 (GND)
IMU_INT: AC2.B1 (INT1), IC2.H2 (P0.18)
LED_EN: IC2.C7 (P0.01/XL2), U3.B2 (EN)
unnamed: BAT-.TP, U1.2 (GND), U1.3 (GND)
unnamed: IC2.A5 (P0.30/AIN6), TX.TP
unnamed: IC2.B3 (P0.25), RX.TP
unnamed: C4.2, IC2.A1 (XC2), X1.1
unnamed: C7.1, IC2.A2 (DEC2)
unnamed: C1.2, IC2.B2 (XC1), X1.3 (2)
unnamed: C5.1, IC2.D1 (ANT), L2.2
unnamed: C6.1, IC2.C2 (DEC3)
unnamed: IC3.D1 (TS/MR), R9.2
unnamed: ANT1.1 (FEED), L2.1
unnamed: C11.1, IC2.B7 (DEC1)
unnamed: C10.1, IC2.A6 (DEC4)
PMIC_INT: IC2.H4 (P0.15), IC3.A1 (!INT), R1.1
PPG_INT: IC1.13 (!INT), IC2.F7 (P0.06), R4.1
RESET: IC2.H1 (P0.21/RESET), J1.3
SCL: AC2.B2 (SCL), IC1.2 (SCL), IC2.A3 (P0.28/AIN4), IC3.B1 (SCL), R2.1, SCL.TP
SDA: AC2.C2 (SDA), IC1.3 (SDA), IC2.A4 (P0.29/AIN5), IC3.C1 (SDA), R3.1, SDA.TP
SWDCLK: IC2.F1 (SWDCLK), J1.4
SWDIO: IC2.G1 (SWDIO), J1.2
VBAT: BAT+.TP, C12.2, C20.2, C37.2, IC3.C2 (BAT), U1.1 (VDD), U3.A2 (IN), U4.A2 (IN)
VBAT_EN: IC2.D7 (P0.00/XL1), U4.B2 (EN)
VBAT_MEAS: C21.2, IC2.E7 (P0.05/AIN3), R5.1, R6.2
VBAT_OUT: R5.2, U4.A1 (OUT)
VLED: C8.2, C14.2, C16.1, IC1.9 (VLED+_1), IC1.10 (VLED+_2), U3.A1 (OUT)
VSYS: C3.2, C39.1, IC3.B2 (SYS), U2.3 (CE), U2.4 (VIN)

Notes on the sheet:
T_sample > 3ns
Main Board
drawn by: Dan Tudose
IMU
PPG
VBAT Measure
MCU
Programming & Test Pads
LDO
Battery Protection
LiPo Charger

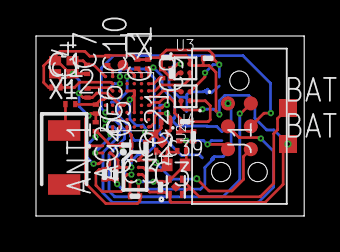
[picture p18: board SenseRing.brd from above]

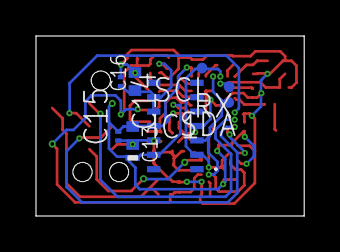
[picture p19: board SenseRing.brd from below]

Board: 2 copper layers, 14.9 x 10.0 mm, 47 parts (9 on the bottom side), 30 nets.

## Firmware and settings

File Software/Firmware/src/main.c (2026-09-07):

/* Boot and the measurement cycle. See ARCHITECTURE.md §5 for the duty-cycle
 * budget and the degraded-mode reasoning.
 */
#include <errno.h>
#include <stdlib.h>
#include <string.h>
#include <zephyr/kernel.h>
#include <zephyr/drivers/hwinfo.h>
#include <zephyr/drivers/i2c.h>
#include <zephyr/logging/log.h>
#include <zephyr/settings/settings.h>
#include <zephyr/sys/printk.h>
#include <zephyr/sys/util.h>
#include "battery.h"
#include "ble.h"
#include "flash_store.h"
#include "imu.h"
#include "ppg.h"
#include "vitals.h"
#include "wallclock.h"

LOG_MODULE_REGISTER(main, LOG_LEVEL_INF);

#define PPG_POLL_INTERVAL_MS 200

/* ==========================================================================
 * Bench switches.
 *
 * These modify the real firmware rather than replacing it, and that is the
 * whole point. 
 * ========================================================================== */

/* Shorten the pause between bursts so the pipeline turns over in seconds.
 *
 * **This switch alone moves nothing else.** PREPARE and REPORT are the
 * measurement itself and keep their shipping lengths, so the readings are the
 * real ones and only their spacing changes. The pause is the one phase that
 * trades against nothing but battery (see PAUSE_MS below), which is exactly what
 * makes it safe to compress here and pointless to compress in a shipping
 * build.
 *
 * BENCH_SYNTHETIC_VITALS *does* also compress the burst, because with fabricated
 * readings there is no measurement left to distort -- see REPORT_MS below.
 */
#define BENCH_FAST_CYCLE 0

/* Feed the pipeline fabricated readings instead of the optics.
 *
 * No LEDs, no finger, no contact gate: the PPG is never started. What does run
 * is everything downstream of vitals_compute() -- the confidence gate, the
 * flash append, the refusal path and the BLE notification. That is the half of
 * this firmware a bench test cannot otherwise reach without somebody wearing
 * the ring for hours, and it is the half that buffer-and-flush actually
 * consists of.
 */
#define BENCH_SYNTHETIC_VITALS 0

#if BENCH_SYNTHETIC_VITALS
/* A plausible resting rate, swung slowly, so a console full of fabricated
 * readings still looks like something a wearer could have produced. The range
 * matters only for readability: nothing downstream judges the number.
 */
#define BENCH_SWEEP_MIN_BPM  58
#define BENCH_SWEEP_MAX_BPM  82
#define BENCH_SWEEP_STEP_BPM 4
#endif

#define BENCH_ANY (BENCH_FAST_CYCLE || BENCH_SYNTHETIC_VITALS)

/* ==========================================================================
 * Live streaming
 *
 * With this at 0 the radio carries **nothing per reading**. Data leaves the ring
 * in page-sized batches: the log fills a 4KB page, main.c nudges, the phone asks
 * for the replay, and the phone acknowledges it. One page is 256
 * records, about 1h43m at the shipping cadence.
 *
 * Turn it on for bench work and for anything that wants to watch readings
 * arrive in real time. The app's live tiles are driven by this stream and by
 * nothing else -- replayed records are charted and stored but deliberately do
 * not move the live tiles, because they are history rather than the wearer's
 * current state.
 * ========================================================================== */
#define BLE_LIVE_STREAM 0

/* One measurement cycle, in phases.
 *
 *   PREPARE  fill the window; nothing can be judged until it is full
 *   REPORT   a package every RECORD_INTERVAL_MS, each from the newest window
 *   PAUSE    LEDs down
 *
 * PREPARE is not idle time -- it is the window itself. vitals_compute() reads a
 * whole VITALS_WINDOW_SEC of signal, so the first package of a cycle cannot
 * exist until that much has been collected, and the assert says so.
 */
#define PREPARE_MS 15000

/* **The burst is compressed only when the readings are fabricated**, and the
 * distinction is the whole safety of doing it at all.
 *
 * With real optics these two numbers are not pacing, they are the measurement:
 * a package is computed from a 15s window of signal, and RECORD_INTERVAL_MS is
 * how far that window slides between packages. Shortening it there would not
 * produce packages faster, it would produce the *same* window reported more
 * often -- five near-identical readings that look like five measurements.
 *
 * Under BENCH_SYNTHETIC_VITALS there is no window and no signal; record_burst()
 * invents each reading, so the interval is pure spacing and can be anything.
 * Making it 100ms turns a cycle from 18s into 3s and a full 4KB page from ~15.5
 * minutes into ~2.6, which is the difference between watching the page nudge
 * happen and waiting for it.
 */
#if BENCH_SYNTHETIC_VITALS
#define REPORT_MS          500
#define RECORD_INTERVAL_MS 100
#else
#define REPORT_MS          15000
#define RECORD_INTERVAL_MS 3000
#endif

/* ]The pause is the only knob that trades battery against nothing
 * else at all: the burst above still produces its five packages, they just
 * arrive every two minutes instead of every one. 90s is 25% duty.
 */
#if BENCH_SYNTHETIC_VITALS
#define PAUSE_MS 2500
#elif BENCH_FAST_CYCLE
#define PAUSE_MS 3000
#else
#define PAUSE_MS 90000
#endif

BUILD_ASSERT(PREPARE_MS >= VITALS_WINDOW_MS,
             "prepare phase shorter than the window: the first package would be computed "
             "from a partly-filled window");
BUILD_ASSERT(REPORT_MS % RECORD_INTERVAL_MS == 0, "report phase is not a whole number of packages");

/* Successive packages inside a burst come from windows that overlap by
 * VITALS_WINDOW_SEC - RECORD_INTERVAL_MS. That is deliberate and worth being
 * explicit about: they are five views of a sliding 15s window, not five
 * independent measurements, so five agreeing packages are weaker evidence than
 * five independent ones would be. Anything reading this log downstream should
 * treat a burst as one measurement seen five times, not as five.
 */
BUILD_ASSERT(RECORD_INTERVAL_MS < VITALS_WINDOW_MS, "packages would have gaps between them");

/* The sliding window and the drain buffer, and everything that fills them, is
 * compiled out under BENCH_SYNTHETIC_VITALS -- that mode never starts the
 * optics, so this would be 3.2KB of RAM held for a sensor it does not read.
 * On a part with 64KB total that is worth reclaiming rather than trusting the
 * linker to notice.
 */
#if !BENCH_SYNTHETIC_VITALS
static struct ppg_sample window[VITALS_WINDOW_SAMPLES];
static size_t window_filled;

static struct ppg_sample batch[32];
#endif

/* Whether the ring is on a finger, as of the last drain. vitals_contact() is
 * stateless and hysteretic, so the belief lives here.
 */
static bool worn;

/* The one place `worn` changes, so the transition can be announced exactly
 * once. A ring coming off a finger is the difference between "no readings
 * because there is nothing to read" and "no readings because something is
 * wrong", and the phone cannot tell those apart on silence alone.
 */
static void set_worn(bool now)
{
    if (now == worn) {
        return;
    }
    worn = now;
    ble_notify_alert(now ? BLE_ALERT_WORN : BLE_ALERT_NOT_WORN);
}

/* Set once battery_init() succeeds; read back by the flush callback below. */
static bool battery_ready;

/* Set once the IMU came up and started. Unlike the PPG the accelerometer is
 * left running for the whole session rather than duty-cycled: in LPM at 50Hz it
 * costs ~15uA against a ~290uA budget (ARCHITECTURE.md §3A.5, §5.1.1), which is
 * far less than the bookkeeping to switch it on and off would be worth. It is
 * also what would let a future wake-on-motion path exist at all.
 */
static bool imu_ready;

/* The median of `n` per-drain movement deltas, in milli-g, or 0 when there are
 * none. Shared by the two places that ask "was the hand moving for most of
 * this?" -- the gate that judges a filled window, and the watch that decides
 * when to start one -- so the two cannot answer the same question differently.
 *
 * Computed by bisecting the value space rather than by sorting a copy: 16
 * passes over 75 uint16s beats 150 bytes of stack and a qsort on a device that
 * has caught a stack overflow before. The caller's array is not disturbed.
 *
 * On an even count this returns the *upper* of the two middle values, which
 * errs toward refusing. That is the same direction the threshold itself errs
 * in.
 */
static uint16_t median_milli_g(const uint16_t *slot, size_t n)
{
    uint32_t lo = 0;
    uint32_t hi = UINT16_MAX;

    if (n == 0) {
        return 0;
    }

    /* The smallest value v for which more than half the samples sit at or
     * below v. Invariant: the answer is always within [lo, hi].
     */
    while (lo < hi) {
        uint32_t mid = lo + (hi - lo) / 2u;
        size_t at_or_below = 0;

        for (size_t i = 0; i < n; i++) {
            if (slot[i] <= mid) {
                at_or_below++;
            }
        }

        if (at_or_below > n / 2u) {
            hi = mid;
        } else {
            lo = mid + 1u;
        }
    }

    return (uint16_t)lo;
}

#if !BENCH_SYNTHETIC_VITALS
/* ==========================================================================
 * How much the hand moved while the window was filling
 *
 * **Why this exists: without it a worn session comes back bimodal.** In one
 * measured session, 88 of 102 accepted readings formed a smooth trace at
 * 71-83bpm and 14 sat in an island at 52-59 -- and the islands are not slow
 * stretches of the same trace, they are discontinuities. Two readings one PAUSE
 * apart gave 57 and 82, with the step counter frozen either side. Some of the
 * islands also arrived with perfusion at 0.9-1.1% against 0.2-0.3% for the
 * whole rest of the session: a pulse does not get five times stronger for four
 * windows and then return, but a hand moving does exactly that to the AC
 * term.
 *
 * **Nothing in the signal path could reject any of it, and that is structural
 * rather than a tuning miss.** `estimate_bpm()` measures periodicity, and
 * rhythmic hand movement is periodic -- every one of those windows cleared
 * VITALS_BPM_CONFIDENCE_MIN, at 526 to 637. The high-pass cannot help either:
 * VITALS_HP_CORNER_BPM is 40, so the filter is deliberately flat across
 * 0.7-1.5Hz, which is 42-90bpm -- where both hand movement and ordinary resting
 * rates live. There is no filter setting that separates them, because in the
 * optics they are the same signal.
 *
 * So the evidence has to come from a different part. The accelerometer already
 * runs continuously (see imu_ready) and `wait_until_worth_probing()` already
 * uses the Manhattan delta between consecutive reads as its movement measure;
 * this is that same quantity, accumulated across the window the optics filled
 * rather than sampled once per package.
 *
 * Sampled in drain_once(), which is the only thing that paces a window, so the
 * movement history and the sample history advance together by construction.
 * ========================================================================== */

/* One slot per drain, covering a whole VITALS_WINDOW_MS at PPG_POLL_INTERVAL_MS
 * each. Rounded up, so the movement history is never shorter than the sample
 * history it has to explain.
 */
#define MOVE_SLOTS ((VITALS_WINDOW_MS + PPG_POLL_INTERVAL_MS - 1) / PPG_POLL_INTERVAL_MS)

static uint16_t move_slot[MOVE_SLOTS]; /* Manhattan delta, milli-g, per drain */
static size_t move_next;               /* where the next delta lands */
static size_t move_filled;             /* slots written since the window reset */
static struct imu_sample move_prev;    /* the reading the next delta is against */
static bool move_have_prev;

static void movement_reset(void)
{
    move_next = 0;
    move_filled = 0;
    move_have_prev = false;
}

/* One drain's worth of movement. Silent on every failure -- a bus glitch or an
 * -EAGAIN is not evidence that the hand was still, and recording a zero for it
 * would be exactly the wrong way to be wrong: it would dilute the mean below
 * and make a contaminated window look usable. A missed read simply does not
 * appear in the history, and the mean is over what was actually measured.
 */
static void movement_sample(void)
{
    struct imu_sample now;
    uint32_t delta;

    if (!imu_ready || imu_read(&now) != 0) {
        return;
    }

    if (move_have_prev) {
        delta = (uint32_t)(abs(now.x - move_prev.x) + abs(now.y - move_prev.y) +
                           abs(now.z - move_prev.z));

        move_slot[move_next] = (uint16_t)MIN(delta, UINT16_MAX);
        move_next = (move_next + 1u) % ARRAY_SIZE(move_slot);
        if (move_filled < ARRAY_SIZE(move_slot)) {
            move_filled++;
        }
    }

    move_prev = now;
    move_have_prev = true;
}
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
int main(void)
{
    LOG_INF("SenseRing v29 System Booting...");

    /* Second line out, before anything else can fail and bury it. Whatever else
     * this boot turns out to be, why it happened is the thing a log read after
     * the fact needs first.
     */
    log_reset_cause();

#if BENCH_ANY
    /* Said once, loudly, because everything after it is a bench run and not the
     * product: a console read from the middle of a session should never leave
     * anyone guessing which one they are looking at.
     */
    LOG_WRN("BENCH BUILD -- fast cycle %s, synthetic vitals %s. Not the shipping cadence.",
            BENCH_FAST_CYCLE ? "on" : "off", BENCH_SYNTHETIC_VITALS ? "on" : "off");
#endif

    /* Bring the battery monitor up first so the boot flush can log a level.
     * A dead battery monitor is no reason to stop reporting a pulse.
     */
    battery_ready = (battery_init() == 0);
    if (!battery_ready) {
        LOG_ERR("Battery monitor unavailable, continuing without it");
    }

    /* Erases last run's log before we start a new one, and says how many
     * records that cost (flash_store.c, count_records_on_part).
     *
     * **It does not dump them first.** "Dumped and erased" and "erased" are the
     * difference between a reset that costs a console scroll and one that costs
     * the data outright -- and with RTT unavailable on a worn ring, a dump here
     * would reach nobody anyway.
     */
    {
        struct boot_state prev;
        uint32_t newest = 0;

        boot_state_load(&prev);

        if (flash_store_init(flush_battery_mv, step_total, prev.generation, &newest) != 0) {
            LOG_ERR("Vitals log unavailable, continuing without it");
        } else if (newest > 0) {
            /* The log was kept. Rebase above its newest record so the next one
             * written cannot collide with or precede it, then put the anchor
             * back so those records are datable before any phone connects.
             * A cold boot leaves `newest` at 0 and both of these untouched.
             */
            wallclock_rebase(newest + 1);
            wallclock_restore(prev.epoch_at_boot_ms);
        }

        s_boot_saved = prev;
        boot_state_save_if_changed();
    }

    /* Everything about this boot that a phone can be told, handed over before
     * the link exists so the very first control read after a reset already
     * carries it. Both terms are ready by here: the cause was stashed at the
     * top of main(), and the erase count is only known once flash_store_init()
     * has decided whether the log survived.
     *
     * This is the only field-visible account of a reset: `Reset cause:` goes to
     * RTT, and a reset on a worn ring is not tethered.
     */
    /* Needs settings, which boot_state_load() above has already brought up, and
     * needs the reset cause, which was stashed at the top of main(). Both are
     * true by here and neither is anywhere else in this function.
     */
    flat_mark_check(s_reset_cause, s_reset_cause_valid);

    ble_set_boot_report(s_reset_cause, s_reset_cause_valid, flash_store_boot_destroyed());
    ble_set_flat_report(s_went_flat, s_flat_mark.percent, s_flat_mark.millivolts,
                        s_flat_mark.epoch_ms);

    /* Connectivity is a bonus on top of the RTT line, never a gate on it. */
    if (ble_init() != 0) {
        LOG_ERR("Bluetooth unavailable, continuing without it");
    }

    /* Same posture as the battery monitor and the log: a degraded feature, not
     * a dead device. A ring that reports a pulse but no movement is worth far
     * more than one that refuses to boot. Started once and left running -- see
     * imu_ready above for why it is not duty-cycled.
     */
    /* Split rather than `imu_init() == 0 && imu_start() == 0` so the console
     * says which half failed. The two have completely different causes -- init
     * is "is the right part there and healthy", start is "did it accept the
     * configuration and begin converting" -- and collapsing them into one line
     * throws away the only clue.
     */
    if (imu_init() != 0) {
        LOG_ERR("IMU init failed -- no motion data this session");
    } else if (imu_start() != 0) {
        LOG_ERR("IMU start failed -- no motion data this session");
    } else {
        imu_ready = true;
    }

    if (ppg_init() != 0) {
        LOG_ERR("PPG Initialization failed!");
#if !BENCH_SYNTHETIC_VITALS
        return 0;
#else
        /* Not fatal here, and that is the point of the mode: it exercises the
         * pipeline downstream of the optics, so it has to run on a board whose
         * optics are absent, unpowered or broken. Refusing to boot would make
         * the one part still under test untestable.
         */
        LOG_WRN("Continuing anyway -- synthetic vitals do not need the optics");
#endif
    }

    while (1) {
        /* Whatever the phone acknowledged while we were measuring or paused:
         * take the space back, and erase a few of the pages it freed.
         *
         * **At the top of the loop, deliberately, and not beside the log dump
         * below.** A ring that is off the finger `continue`s before reaching
         * the dump, and that is the path that matters: a ring in a pocket
         * overnight measures nothing for hours while
         * a connected phone goes on collecting and acknowledging the backlog.
         * Housekeeping that only runs on cycles that measured something would
         * leave those pages unerased for exactly as long as the wearer was not
         * wearing it.
         *
         * The LEDs are down at this point and the sensor is stopped, so the
         * erases cost measurement nothing beyond delaying the next burst. They
         * are bounded per call for that reason (flash_store.h).
         */
        flash_store_service();

        /* **Battery first, and on every cycle.** It used to be read after the
         * measurement and only when the ring was worn, which made it invisible
         * on exactly the two paths that matter: a ring off the finger, and a
         * ring that has stopped measuring *because* the cell is low. The second
         * is self-locking -- stop measuring on a low battery, never read the
         * battery again, never notice it was charged.
         */
        power_check();

        /* Out of cell. Measuring is over; delivering what was already measured
         * is not.
         *
         * The ring holds up to four days of readings that exist nowhere else,
         * so the worst end to a wear test is dying with a full buffer. Below
         * the critical mark it stops taking new readings -- which is what costs
         * the battery -- and keeps only the radio, nudging the phone so the
         * backlog has every chance to leave before the lights go out. Readings
         * lost to not measuring are readings that were never taken; readings
         * lost with the buffer are readings taken and then destroyed.
         */
        if (s_power == POWER_CRITICAL) {
            nudge_if_backlog_deep();
            boot_state_save_if_changed();
            k_msleep(POWER_CRITICAL_SLEEP_MS);
            continue;
        }

        measurement_cycle();

        /* Nothing was measured, so there is nothing to report on and no reason
         * to spend a battery reading or a log dump on it. Wait for the ring to
         * be picked up instead -- that wait is where the responsiveness on
         * re-donning comes from, and skipping the housekeeping is also what
         * keeps a fast retry from filling the console with empty dumps.
         */
        if (!worn) {
            wait_until_worth_probing();
            continue;
        }

        /* Read the log back without erasing it, once per cycle. A liveness
         * check, not part of the storage contract: it proves packages are being
         * measured and stored and that the battery still reads, on a console
         * that is otherwise silent for hours.
         *
         * Only what is new since the last dump -- a handful of lines a cycle,
         * forever. It cannot print the whole log instead: the RTT up-buffer is
         * 1KB in NO_BLOCK_SKIP mode, about 13 of these lines, and a burst past
         * that is dropped with no marker at all.
         */
        (void)flash_store_dump();
        bench_report_backlog();
        nudge_if_backlog_deep();
        boot_state_save_if_changed();
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

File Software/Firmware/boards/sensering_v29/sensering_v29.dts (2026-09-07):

/dts-v1/;
#include <nordic/nrf52832_qfaa.dtsi>
#include <zephyr/dt-bindings/adc/adc.h>

/ {
    model = "SenseRing v29";
    compatible = "sensering,sensering-v29";

    chosen {
        zephyr,sram = &sram0;
        zephyr,flash = &flash0;
        /* Keep the settings/NVS backend off the vitals-log partition. Without
         * this it defaults to storage_partition, which flash_store.c erases at
         * boot and laps over in normal running -- taking the BLE bond keys
         * with it.
         */
        zephyr,settings-partition = &settings_partition;
    };

    /* Updated hardware-aware mapping for your load switches */
    power_switches {
        compatible = "gpio-leds";
        led_en_switch: switch_1 {
            gpios = <&gpio0 1 GPIO_ACTIVE_HIGH>; /* Moved from P0.10 -> P0.01 */
            label = "VLED Rail Load Switch Enable";
        };
        vbat_en_switch: switch_2 {
            gpios = <&gpio0 0 GPIO_ACTIVE_HIGH>; /* Moved from P0.09 -> P0.00 */
            label = "Battery Voltage Divider Enable";
        };
    };

    /* Explicitly mapping the hardware interrupt inputs to give names to pins */
    interrupt_signals {
        compatible = "gpio-keys";
        ppg_int_pin: int_ppg {
            gpios = <&gpio0 6 (GPIO_ACTIVE_LOW | GPIO_PULL_UP)>;
            label = "MAX30102 Interrupt Line";
        };
        pmic_int_pin: int_pmic {
            gpios = <&gpio0 15 (GPIO_ACTIVE_LOW | GPIO_PULL_UP)>;
            label = "BQ25180 PMIC Interrupt Line";
        };
        imu_int_pin: int_imu {
            gpios = <&gpio0 18 (GPIO_ACTIVE_LOW | GPIO_PULL_UP)>;
            label = "BMA530 IMU Interrupt Line";
        };
    };

    /* The cell reaches this divider only while vbat_en_switch holds U4 on, so
     * the legs below burn 1.7uA during a reading and nothing at all between
     * them. The tap sits on AIN3.
     */
    vbat: vbat {
        compatible = "voltage-divider";
        io-channels = <&adc 3>;
        output-ohms = <1000000>;  /* R6 */
        full-ohms = <2500000>;    /* R5 (1M5) + R6 (1M) */
    };
};

&flash0 {
    partitions {
        compatible = "fixed-partitions";
        #address-cells = <1>;
        #size-cells = <1>;

        boot_partition: partition@0 {
            label = "mcuboot";
            reg = <0x00000000 0xc000>;
        };
        slot0_partition: partition@c000 {
            label = "image-0";
            reg = <0x0000c000 0x32000>;
        };
        /* What used to be image-1 (200KB) and image-scratch (32KB) is now the
         * vitals log. MCUboot is not built and nothing links against these
         * slots (ARCHITECTURE.md App. C), so before this they were 232KB of
         * flash the device carried and never touched.
         *
         * **The trade, made deliberately: this gives up OTA updates** unless the
         * space is reclaimed later. What it buys is buffer depth -- the ring
         * goes from ~8.6 hours uncollected to a bit over four days, which is
         * the difference between a wearer who leaves their phone charging
         * overnight losing the early hours of a night and losing nothing.
         * That failure is specific and plausible; a firmware update path that
         * has never been built is not.
         *
         * Reclaiming it later means shrinking this back to 0x6000 at 0x7a000
         * and restoring the two slots. Records are RAM-addressed by sequence
         * number and erased at boot, so nothing on flash has to migrate.
         */
        storage_partition: partition@3e000 {
            label = "storage";
            reg = <0x0003e000 0x3a000>;
        };
        /* NVS-backed settings store for BLE bond keys (see CONFIG_BT_SETTINGS).
         * Two pages is the NVS minimum: the backend needs at least two 4KB
         * erase sectors for its garbage collection.
         *
         * **Deliberately left where it was.** The obvious tidier layout moves
         * this to the end and lets storage run contiguously to 0x80000, but the
         * NVS content is addressed by partition offset: moving it discards every
         * stored bond *and* the BLE identity address, so every paired phone
         * would need re-pairing and every standing auto-connect request would be
         * waiting for a peer that no longer exists (§5B.5). Twenty-four
         * kilobytes of buffer is not worth that.
         */
        settings_partition: partition@78000 {
            label = "settings";
            reg = <0x00078000 0x2000>;
        };
        /* 0x7a000-0x80000 is the old 24KB storage partition, now unallocated.
         * It is stranded on the far side of `settings` and cannot be merged
         * into the log, which has to be one contiguous flash area. Left out of
         * the table rather than relabelled, so it reads as spare rather than as
         * something with a purpose.
         */
    };
};

&gpio0 {
    status = "okay";
};

&gpiote {
    status = "okay";
};

&adc {
    status = "okay";
    #address-cells = <1>;
    #size-cells = <0>;

    /* The divider scales a full 4.2V cell down to 1.68V, so 1/3 gain against
     * the internal 0.6V reference gives a 1.8V full scale that covers the cell
     * with a little room left over. R5 and R6 in parallel present 600k to the
     * SAADC, which is why the sampling capacitor needs the longest acquisition
     * window the peripheral offers.
     */
    channel@3 {
        reg = <3>;
        zephyr,gain = "ADC_GAIN_1_3";
        zephyr,reference = "ADC_REF_INTERNAL";
        zephyr,acquisition-time = <ADC_ACQ_TIME(ADC_ACQ_TIME_MICROSECONDS, 40)>;
        zephyr,input-positive = <NRF_SAADC_AIN3>;
        zephyr,resolution = <12>;
        /* The PPG pulses ~10mA of LED drive off the same cell, so average 16
         * conversions to keep that ripple out of the reading.
         */
        zephyr,oversampling = <4>;
    };
};

/* Shared I2C (TWI) Bus Mapping using your updated hardware boundaries */
&i2c0 {
    status = "okay";
    pinctrl-0 = <&i2c0_default>;
    pinctrl-1 = <&i2c0_sleep>;
    pinctrl-names = "default", "sleep";
    clock-frequency = <I2C_BITRATE_FAST>; /* 400 kHz bus clock speed */

    max30102: max30102@57 {
        compatible = "i2c-device";
        reg = <0x57>;
        label = "MAX30102_PPG";
    };

    /* The v49 schematic (designator AC2) fits a BMA530, not the BMA456 this
     * node used to claim. Different part, different generation, incompatible
     * register map. 0x18 is the BMA530's fixed default address -- the 6-ball
     * WLCSP exposes no SDO pin, so unlike the BMA456 there is nothing to strap.
     */
    bma530: bma530@18 {
        compatible = "i2c-device";
        reg = <0x18>;
        label = "BMA530_IMU";
    };
};
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

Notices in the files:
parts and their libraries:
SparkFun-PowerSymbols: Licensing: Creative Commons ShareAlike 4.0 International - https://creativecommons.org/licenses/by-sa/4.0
